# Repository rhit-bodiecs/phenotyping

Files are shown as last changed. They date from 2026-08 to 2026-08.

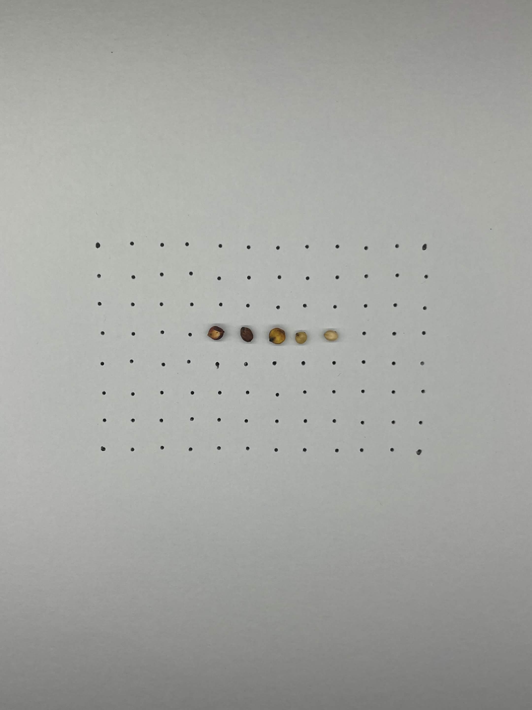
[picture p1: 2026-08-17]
ImageProcessing/demo.jpg

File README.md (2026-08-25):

# Sorghum Seed Phenotyping Automation

This repository contains prototype code and hardware design files for improving a sorghum seed phenotyping imaging pipeline.

The motivation for the project is to reduce the manual bottleneck in preparing seed samples for imaging. The current workflow requires opening a labeled packet, pouring approximately 100 seeds onto an imaging tray, manually spreading them so seeds do not touch, taking an image for downstream segmentation, and returning the seeds to the packet. Because the segmentation step expects separated seeds and is not being modified here, the hardware goal is to make seed spacing and collection faster and more repeatable.

## Demo Video

A short demo of the current prototype is available here:

[Seed phenotyping automation prototype demo](https://youtu.be/DYeSpMTDBck)

## Project Concept

The current prototype explores a vacuum-assisted positioning system:

- A perforated imaging surface biases seeds toward individual hole locations.
- A Shark WV201 handheld vacuum provides suction through a custom adapter.
- A rocking or tilting mechanism can move loose seeds around until they settle into available holes.
- After positioning, uncaptured seeds can be dumped into a collection chute while captured seeds remain held by vacuum.
- The system is being designed as modular 3D-printable parts so pieces can be tested and revised independently.

## Repository Layout

```text
.
├── 3d_models/
│   ├── seed_case_print_v1/
│   └── shark_wv201_adapter/
├── ImageProcessing/
├── nucleo-servo/
├── Time_Data.xlsx
└── README.md
```

## 3D Models

The `3d_models/` folder contains OpenSCAD source files and exported STL files from the current hardware prototype work.

### `3d_models/seed_case_print_v1/`

Separated printable parts for the modular seed imaging case and collection frame:

- `top_plate.scad` / `top_plate.stl`
- `front_wall.scad` / `front_wall.stl`
- `back_wall.scad` / `back_wall.stl`
- `left_side_wall.scad` / `left_side_wall.stl`
- `right_side_wall.scad` / `right_side_wall.stl`
- `bottom_collector_frame.scad` / `bottom_collector_frame.stl`

These parts are intended to slide together using tab-and-slot features. The bottom collector frame includes the seed collection funnel/chute and receiver grooves for the wall pieces.

### `3d_models/shark_wv201_adapter/`

Adapter prototypes for connecting the seed tray/funnel system to a Shark WV201 handheld vacuum:

- rectangular adapter prototype
- nozzle fit-test model
- rotating adapter starting model
- separated static and moving rotating-adapter pieces

These files preserve the iterative vacuum-interface work used to test nozzle fit, suction transfer, and the rotating joint concept.

## Firmware / Electronics

The `nucleo-servo/` folder is intended for embedded control work, including servo-based motion experiments. The planned control flow is:

1. Press a button to start the sequence.
2. Turn on vacuum.
3. Rock or tilt the plate to encourage seeds to settle into holes.
4. Rotate/tilt to dump uncaptured seeds into the collector.
5. Return to flat for imaging.

Future work may add camera triggering and automatic image transfer, but the current hardware/control focus is on seed positioning and mechanical automation.

## Image Processing

The `ImageProcessing/` folder contains image-processing work related to extracting phenotype data from seed images. The mechanical prototype is designed around the constraint that the segmentation step works best when seeds are separated and not touching.

## Ignored Local Artifacts

The repository ignores:

- `Figures/`
- `Phenotyping_Automation_Project.pptx`

These files are useful locally for documentation and presentation work but are excluded from version control.

## Bill of Materials

Prototype electronics and hardware links:

| Item | Link |
| --- | --- |
| BOM item 1 | [Amazon ASIN B01I8XLEM8](https://www.amazon.com/dp/B01I8XLEM8) |
| BOM item 2 | [Amazon ASIN B07HNTKSZT](https://www.amazon.com/dp/B07HNTKSZT) |
| BOM item 3 | [Amazon ASIN B08BCBZ632](https://www.amazon.com/dp/B08BCBZ632) |
| BOM item 4 | [Amazon ASIN B01ERP6WL4](https://www.amazon.com/dp/B01ERP6WL4) |

## Next Steps

- Reprint the top plate with a slightly wider/longer tray cutout so the rotating tray has enough clearance. The current printed plate is slightly too small length-wise for smooth tray rotation.
- Revise the funnel/rotating adapter model to include a printed tab at the end of the dowel/axle for connecting to the servo motor tab. The current prototype uses superglue, a loose plastic tab, and a rubber band linkage; integrating this tab directly into the printed model should make the servo linkage more reliable and repeatable.

## Current Prototype Status

The current print-ready mechanical checkpoint is `3d_models/seed_case_print_v1/`. The parts are separated for modular printing and iterative fit testing. The design is still experimental, especially the tab/slot tolerances, collector geometry, and future servo mounting/alignment.

## Tools

Primary tools used so far:

- OpenSCAD for parametric CAD
- STL exports for 3D printing
- Shark WV201 vacuum for suction testing
- STM32/Nucleo-style development target for planned servo control experiments

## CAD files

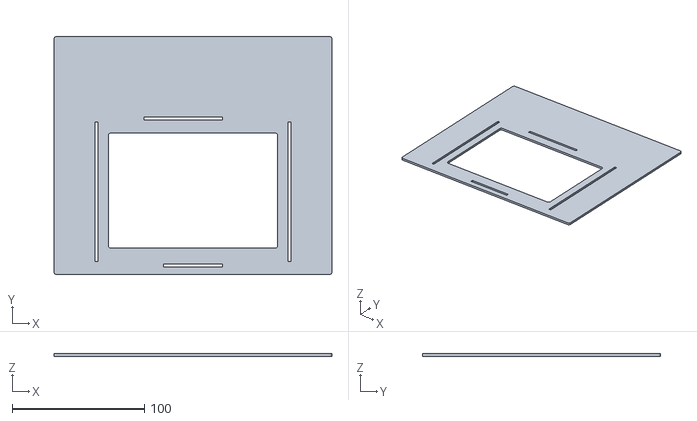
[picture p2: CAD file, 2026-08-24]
3d_models/seed_case_print_v1/top_plate.stl
210.0 x 180.0 x 2.00

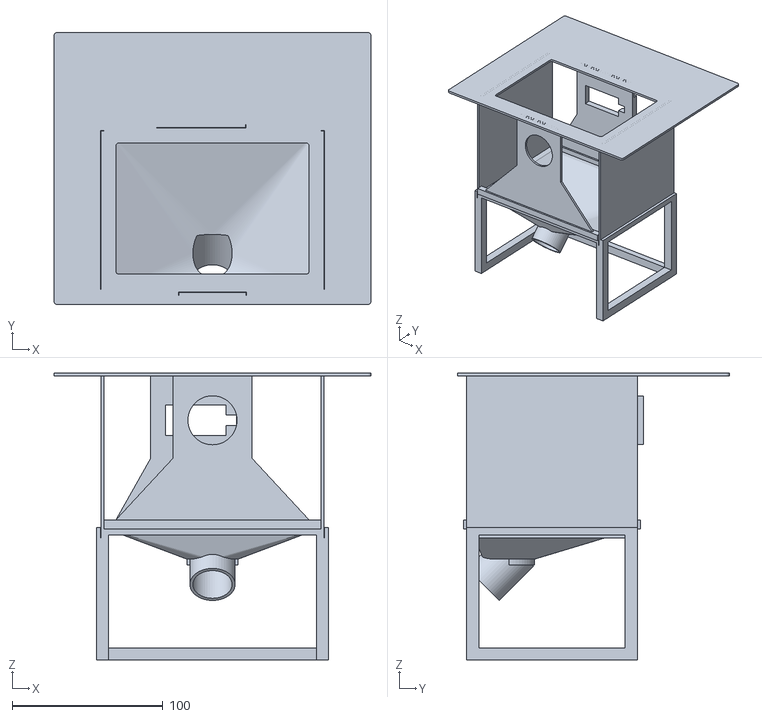
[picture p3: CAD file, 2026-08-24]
3d_models/seed_imaging_system_case_collector_ai_preview.stl
210.0 x 180.0 x 190.0

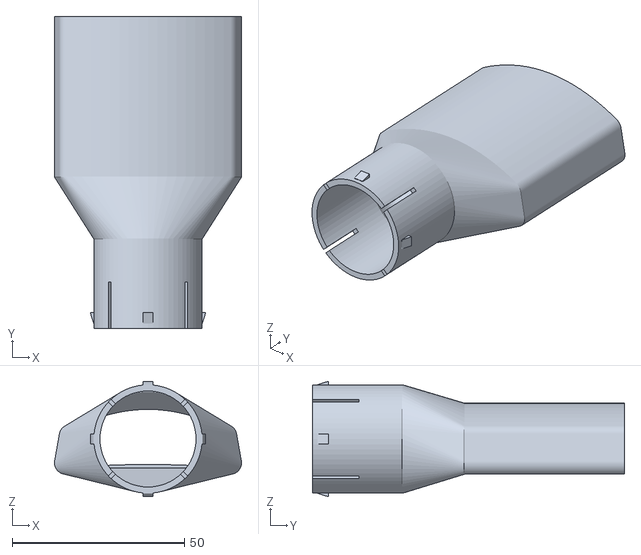
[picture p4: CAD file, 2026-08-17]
3d_models/shark_wv201_adapter/shark_wv201_rotating_adapter_static_piece_preview.stl
54.4 x 90.7 x 33.5

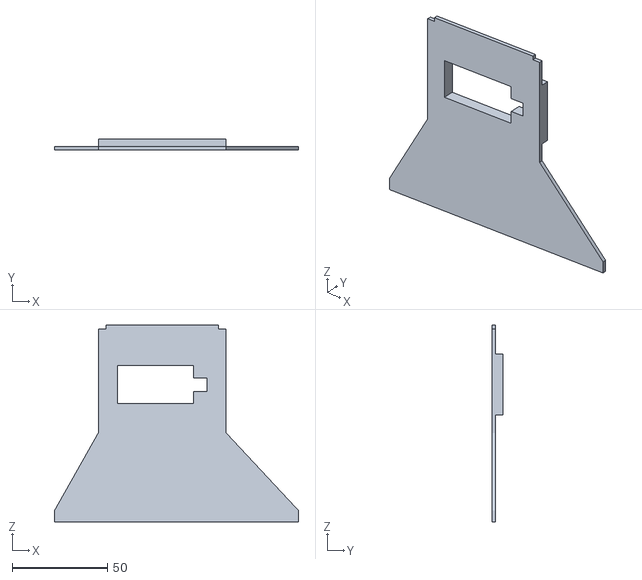
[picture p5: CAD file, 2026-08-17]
3d_models/seed_case_print_v1/back_wall.stl
128.0 x 6.00 x 103.2

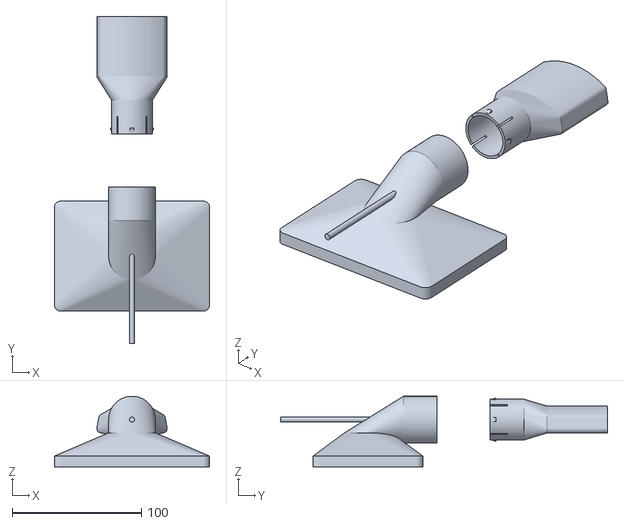
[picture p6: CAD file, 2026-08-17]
3d_models/shark_wv201_adapter/shark_wv201_rotating_adapter_v1_start_preview.stl
120.0 x 252.5 x 54.5

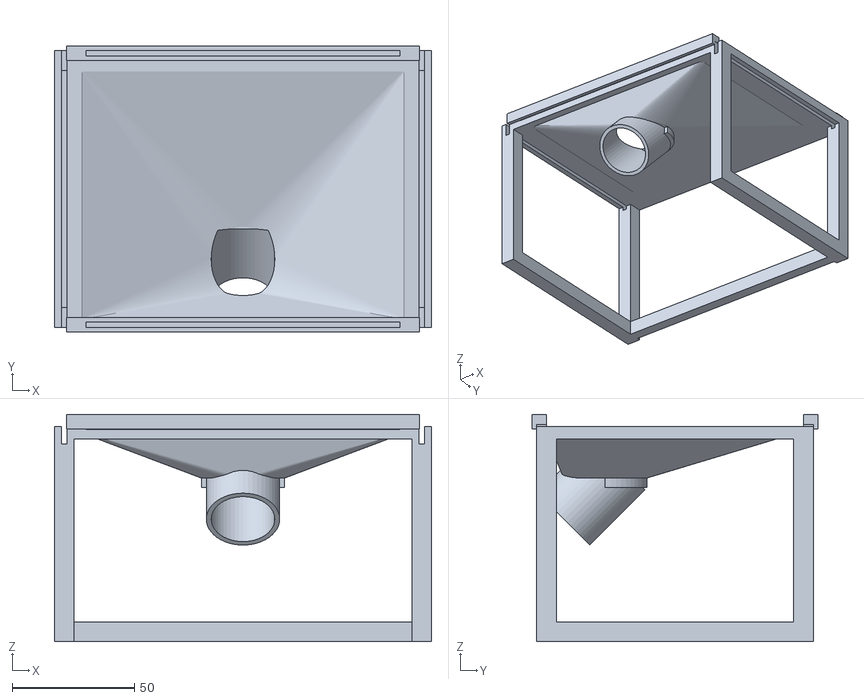
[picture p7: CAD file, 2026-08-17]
3d_models/seed_case_print_v1/bottom_collector_frame.stl
154.0 x 117.0 x 92.8

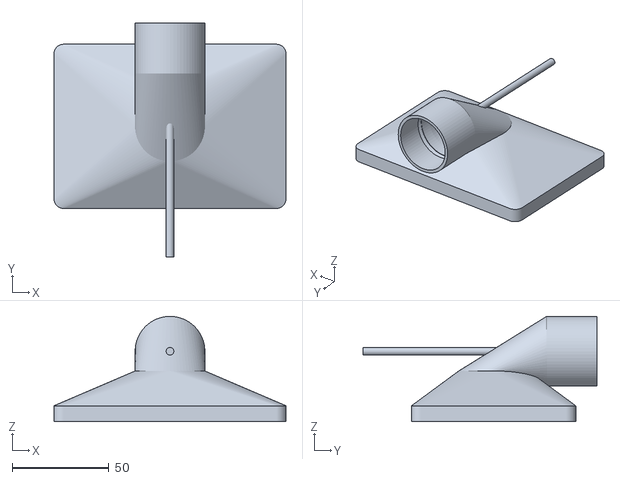
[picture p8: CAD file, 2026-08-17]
3d_models/shark_wv201_adapter/shark_wv201_rotating_adapter_moving_body_preview.stl
120.0 x 120.9 x 54.5

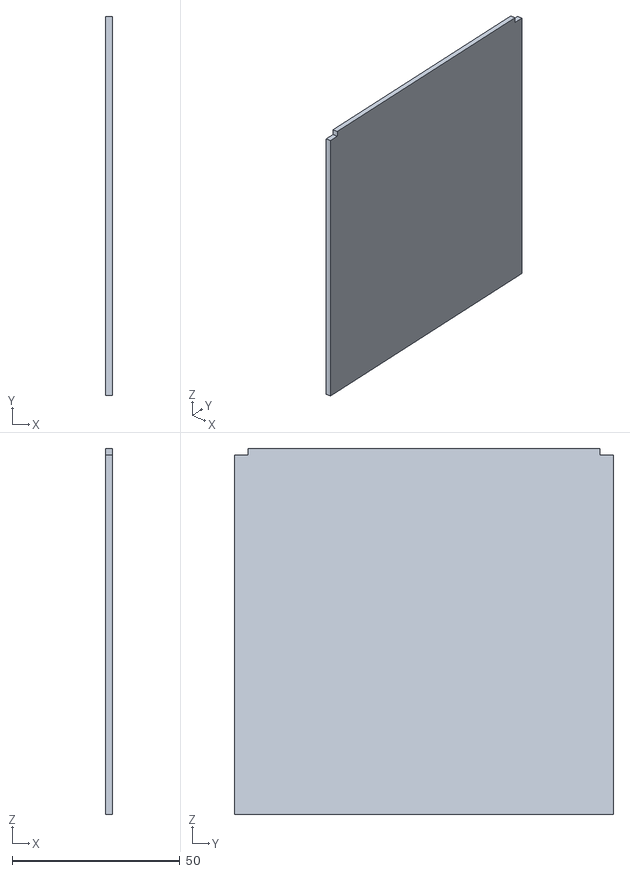
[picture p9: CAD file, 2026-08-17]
3d_models/seed_case_print_v1/left_side_wall.stl
2.00 x 113.0 x 109.2

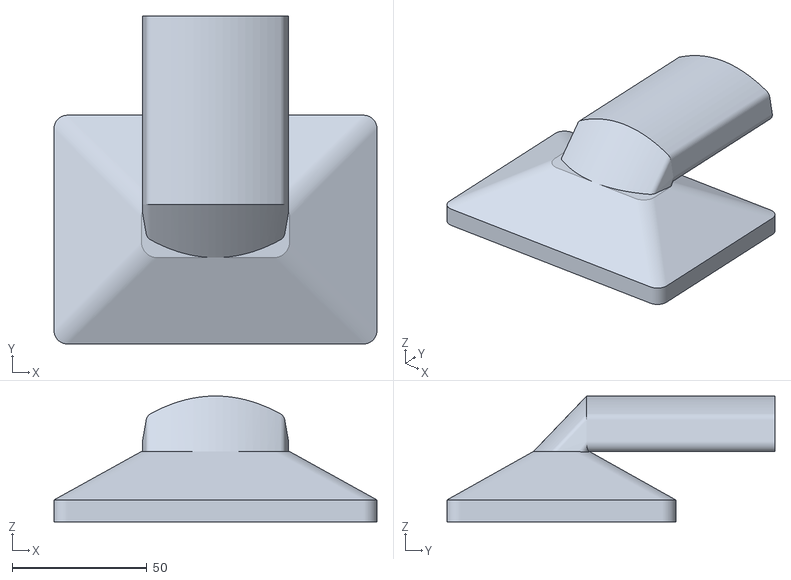
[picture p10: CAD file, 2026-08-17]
3d_models/shark_wv201_adapter/shark_wv201_rectangular_adapter.stl
120.0 x 121.9 x 46.8

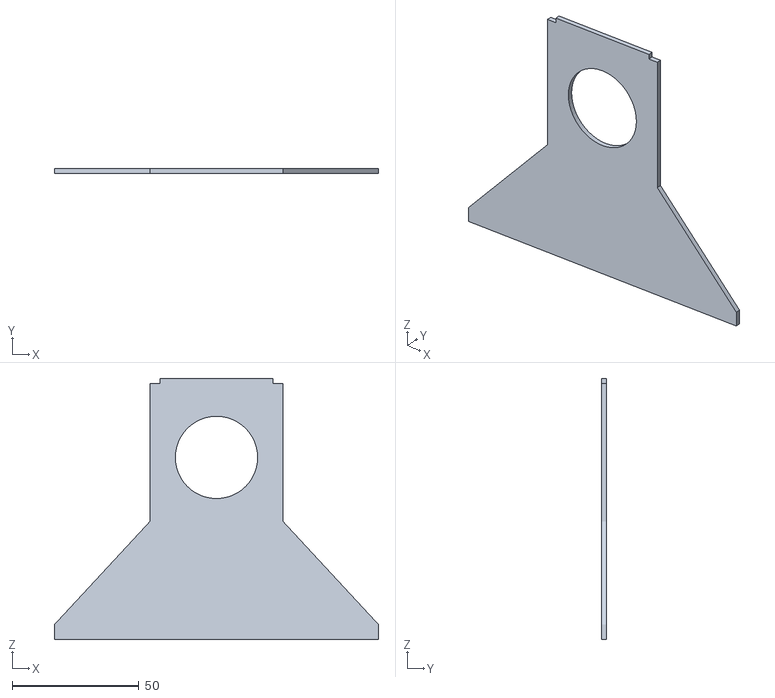
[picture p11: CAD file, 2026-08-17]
3d_models/seed_case_print_v1/front_wall.stl
128.0 x 2.00 x 103.2

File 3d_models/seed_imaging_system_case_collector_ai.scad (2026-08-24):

/*
  Seed imaging system case with experimental collector

  Starting point:
    A simple rectangular base plate for the vacuum/rocking seed imaging system.
*/

$fn = 48;

// Choose what OpenSCAD shows/exports.
part_to_show = "assembly"; // "assembly", "plate", "front", "back", "left_side", "right_side", "sides", "collector", "lower_frame", "bottom"

// Base plate dimensions.
plate_w = 210;      // mm
plate_h = 180;      // mm
plate_thick = 2;    // mm
corner_r = 2;       // mm, just enough to remove sharp corners
wall_slot_clearance = 0.3; // mm extra slot size for sliding wall parts into plate

// Cutout matching the outer tray footprint of the moving funnel adapter.
funnel_cutout_w = 124;       // mm, nominal long side for housing layout
top_plate_cutout_extra_w = 4; // mm, widens only the top plate tray cutout by 2 mm per side
funnel_cutout_h = 87;        // mm, short side plus clearance for rotation
funnel_front_gap = 20;       // mm from front long edge of plate to cutout
funnel_cutout_r = 2;         // mm, slight radius to avoid sharp internal corners
funnel_cutout_y = -plate_h/2 + funnel_front_gap + funnel_cutout_h/2;

// Front wall for the vacuum adapter interface, hanging down from the top plate.
front_wall_offset_from_cutout = 12; // mm from front edge of cutout toward plate front
front_wall_extra_w = 10;            // mm extension beyond each cutout side
front_wall_w = funnel_cutout_w + 2 * front_wall_extra_w;
front_wall_h = 101.25;              // mm, bottom is 72 mm below front circle center
front_wall_thick = 2;               // mm
front_wall_y = funnel_cutout_y - funnel_cutout_h/2 - front_wall_offset_from_cutout - front_wall_thick;
back_wall_offset_from_cutout = 10;  // mm from back edge of cutout toward plate back
back_wall_y = funnel_cutout_y + funnel_cutout_h/2 + back_wall_offset_from_cutout;
side_wall_thick = front_wall_thick;
side_wall_y = front_wall_y;
side_wall_depth = back_wall_y + front_wall_thick - front_wall_y;

// Circular opening in the front wall for the static funnel-system spout.
static_spout_outer_d = 31.5;       // mm, current static male spout OD
front_wall_spout_clearance = 1;    // mm extra diameter clearance
front_wall_spout_cutout_d = static_spout_outer_d + front_wall_spout_clearance;
front_wall_spout_top_drop = 15;    // mm below top surface of plate
front_wall_spout_center_z = plate_thick - front_wall_spout_top_drop - front_wall_spout_cutout_d/2;
front_wall_tab_margin = 10;      // mm material around circular spout tab
front_wall_tab_x = -front_wall_spout_cutout_d/2 - front_wall_tab_margin;
front_wall_tab_w = front_wall_spout_cutout_d + 2 * front_wall_tab_margin;
front_back_wall_bottom_clearance = 10; // mm below circular cutout bottom
front_back_wall_bottom_z = front_wall_spout_center_z - front_wall_spout_cutout_d/2 - front_back_wall_bottom_clearance;
front_back_wall_h = -front_back_wall_bottom_z;

// Rectangular opening in the back wall, aligned with the spout opening height.
back_wall_rect_cutout_w = 40;   // mm, long horizontal edge
back_wall_rect_cutout_h = 20;   // mm, vertical edge
back_wall_rect_cutout_x_shift = -11; // mm, left shift from spout center
back_wall_notch_size = 7;       // mm square notch centered on right edge
back_wall_notch_overlap = 0.5;  // mm overlap to avoid a zero-width seam
back_wall_tab_margin = 10;      // mm material around motor cutout tab
back_wall_cutout_min_x = back_wall_rect_cutout_x_shift - back_wall_rect_cutout_w/2;
back_wall_cutout_max_x = back_wall_rect_cutout_x_shift + back_wall_rect_cutout_w/2 + back_wall_notch_size;
back_wall_tab_x = back_wall_cutout_min_x - back_wall_tab_margin;
back_wall_tab_w = back_wall_cutout_max_x - back_wall_cutout_min_x + 2 * back_wall_tab_margin;
back_wall_servo_pad_thick = 4;    // mm extra thickness behind servo mount area
back_wall_servo_pad_margin = 6;   // mm material around the motor rectangle cutout
// Experimental lower collector dimensions.
total_system_h = 190;              // mm, target total height from top of plate to floor
floor_z = plate_thick - total_system_h;
upper_wall_bottom_z = -front_wall_h;
collector_drop_h = upper_wall_bottom_z - floor_z;
collector_wall = 2;                // mm wall thickness for chute/outlet
collector_outlet_od = 30;          // mm outer diameter for seed packet interface
collector_outlet_id = collector_outlet_od - 2 * collector_wall;
collector_outlet_len = 24;         // mm, angled tube length; shorter leaves room for the funnel slope
collector_neck_overlap = 8;        // mm overlap into throat so the angled neck and funnel connect solidly
collector_outlet_angle = 135;      // degrees; cylinder axis points 45 degrees down toward the front
collector_floor_clearance = 35;    // mm from floor to lowest outside edge of outlet mouth
collector_outlet_end_z = floor_z + collector_floor_clearance + collector_outlet_od/2;
collector_outlet_start_z = collector_outlet_end_z - collector_outlet_len * cos(collector_outlet_angle);
collector_outlet_start_y = front_wall_y + 28;
collector_outlet_end_y = collector_outlet_start_y - collector_outlet_len * sin(collector_outlet_angle);
collector_top_margin = 3;          // mm inset from inside wall span
collector_post = 8;                // mm square lower frame corner posts
collector_base_rail_h = 8;         // mm height of bottom rails
collector_base_rail_thick = 6;     // mm thickness of bottom rails
collector_lip_h = 4;               // mm thick top lip tying collector mouth into lower posts
collector_lip_overlap_up = 1;      // mm overlap into upper walls for preview/alignment before adding slots
bottom_wall_notch_depth = 6;       // mm deep receiver notch for side walls in the bottom piece
side_wall_h = front_wall_h + bottom_wall_notch_depth; // mm side walls extend into bottom notches
side_wall_top_tab_inset = 4;      // mm shorter at each end to make a shoulder stop under the top plate
front_back_wall_top_tab_inset = 4; // mm shorter at each end for front/back top plate shoulder stops
tray_boundary_wall_thick = 6;     // mm, wider than 2 mm front/back walls for future notches
tray_boundary_wall_h = 6;         // mm small raised boundary at front/back tray edges
tray_boundary_wall_x_margin = 4;  // mm extra length beyond matching front/back wall pieces
tray_boundary_wall_side_inset = side_wall_thick/2 + collector_post/2; // mm keeps rails clear of side walls
front_back_diag_frame_w = 8;      // mm width of trapezoid-frame brace bands
front_back_diag_wall_overlap = 1; // mm overlap so brace merges cleanly into front/back wall
front_back_diag_inner_base_inset = 22; // mm larger values make the inner triangle less obtuse
front_back_diag_end_inset = 14;   // mm keeps brace feet shy of side-wall/funnel corners
front_back_diag_tab_w = 12;       // mm width of rectangular feet that seat in tray-wall notches
front_back_diag_tab_h = tray_boundary_wall_h; // mm foot height matching the tray wall height
front_back_diag_notch_clearance = wall_slot_clearance; // mm extra room around brace feet

// Makes a 2D rounded rectangle profile.
module rounded_rect_2d(w, h, r) {
  offset(r = r)
    square([w - 2*r, h - 2*r], center = true);
}

// Makes the main rectangular base plate with lightly rounded corners.
module base_plate() {
  linear_extrude(height = plate_thick)
    rounded_rect_2d(plate_w, plate_h, corner_r);
}

// Cuts the moving funnel adapter tray footprint through the plate. The long
// side of the cutout runs parallel to the long side of the plate.
module funnel_tray_cutout() {
  translate([0, funnel_cutout_y, -0.5])
    linear_extrude(height = plate_thick + 1)
      rounded_rect_2d(funnel_cutout_w + top_plate_cutout_extra_w, funnel_cutout_h, funnel_cutout_r);
}

// Cuts the round spout opening through the front wall.
module front_wall_spout_cutout() {
  translate([0, front_wall_y + front_wall_thick/2, front_wall_spout_center_z])
    rotate([90, 0, 0])
      cylinder(h = front_wall_thick + 1, d = front_wall_spout_cutout_d, center = true);
}


// Makes a trapezoid-shaped wall extension with a triangular center opening.
// The two lower rectangular feet seat into matching notches in the tray wall.
module front_back_trapezoid_brace_at(wall_x, wall_w, y, y_thick) {
  top_left = wall_x;
  top_right = wall_x + wall_w;
  foot_left_center = -front_wall_w/2 + front_back_diag_end_inset;
  foot_right_center = front_wall_w/2 - front_back_diag_end_inset;
  foot_left_outer = foot_left_center - front_back_diag_tab_w/2;
  foot_left_inner = foot_left_center + front_back_diag_tab_w/2;
  foot_right_inner = foot_right_center - front_back_diag_tab_w/2;
  foot_right_outer = foot_right_center + front_back_diag_tab_w/2;
  z_top = front_back_wall_bottom_z + front_back_diag_wall_overlap;
  z_bottom = upper_wall_bottom_z;
  z_foot_top = upper_wall_bottom_z + front_back_diag_tab_h;
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

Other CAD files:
3d_models/seed_case_print_v1/right_side_wall.stl
3d_models/seed_case_print_v1/back_wall.scad
3d_models/seed_case_print_v1/bottom_collector_frame.scad
3d_models/seed_case_print_v1/front_wall.scad
3d_models/seed_case_print_v1/left_side_wall.scad
3d_models/seed_case_print_v1/right_side_wall.scad
3d_models/seed_case_print_v1/top_plate.scad
3d_models/shark_wv201_adapter/shark_wv201_nozzle_fit_test_current.scad
3d_models/shark_wv201_adapter/shark_wv201_rectangular_adapter.scad
3d_models/shark_wv201_adapter/shark_wv201_rotating_adapter_moving_body.scad
3d_models/shark_wv201_adapter/shark_wv201_rotating_adapter_static_piece.scad
3d_models/shark_wv201_adapter/shark_wv201_rotating_adapter_v1_start.scad

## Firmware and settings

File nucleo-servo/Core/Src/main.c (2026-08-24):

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
/* Includes ------------------------------------------------------------------*/
#include "main.h"



TIM_HandleTypeDef htim8;

/* USER CODE BEGIN PV */
static const uint16_t SERVO_MIN_US    = 500U;
static const uint16_t SERVO_CENTER_US = 1500U;
static const uint16_t SERVO_MAX_US    = 2500U;
static const uint16_t SERVO_JITTER_US = 200U;
static const uint16_t SERVO_QUARTER_US = 675U;

static const uint16_t SERVO_START = SERVO_CENTER_US - SERVO_QUARTER_US;
static const uint16_t SERVO_DUMP = SERVO_CENTER_US + SERVO_QUARTER_US;

static const uint16_t JITTER_DELAY = 125;
static const uint16_t JITTER_COUNT = 20;
/* USER CODE END PV */

void SystemClock_Config(void);
static void MX_GPIO_Init(void);
static void MX_TIM8_Init(void);
/* USER CODE BEGIN 0 */
static void servo_write_us(uint16_t pulse_us)
{
    /*
     * Keep the pulse within a conservative initial range.
     * Expand this only after confirming the servo does not hit its stops.
     */		
    if (pulse_us < SERVO_MIN_US) {
        pulse_us = SERVO_MIN_US;
    }

    if (pulse_us > SERVO_MAX_US) {
        pulse_us = SERVO_MAX_US;
    }

    __HAL_TIM_SET_COMPARE(&htim8, TIM_CHANNEL_2, pulse_us);
}

void dump_sequence(void)
{	
	//jitter for about one second
	for(int i = 0; i < JITTER_COUNT; i++){
		servo_write_us(SERVO_START + SERVO_JITTER_US);
		HAL_Delay(JITTER_DELAY);

		servo_write_us(SERVO_START - SERVO_JITTER_US);
		HAL_Delay(JITTER_DELAY);
	}
	
	servo_write_us(SERVO_START);
	HAL_Delay(2000);
	servo_write_us(SERVO_DUMP);
	HAL_Delay(2000);
	servo_write_us(SERVO_START);

}
/* USER CODE END 0 */

/**
  * @brief  The application entry point.
  * @retval int
  */
int main(void)
{

  /* MCU Configuration--------------------------------------------------------*/

  /* Reset of all peripherals, Initializes the Flash interface and the Systick. */
  HAL_Init();

  /* Configure the system clock */
  SystemClock_Config();

  /* Initialize all configured peripherals */
  MX_GPIO_Init();
  MX_TIM8_Init();
  /* USER CODE BEGIN 2 */
if (HAL_TIM_PWM_Start(&htim8, TIM_CHANNEL_2) != HAL_OK) {
    Error_Handler();
}

servo_write_us(SERVO_START);
HAL_Delay(1000);
  /* USER CODE END 2 */

  /* Initialize leds */
  BSP_LED_Init(LED2);

  /* Initialize USER push-button, will be used to trigger an interrupt each time it's pressed.*/
  BSP_PB_Init(BUTTON_USER, BUTTON_MODE_EXTI);

  /* Infinite loop */
  /* USER CODE BEGIN WHILE */
  while (1)
  {
	if(HAL_GPIO_ReadPin(GPIOC, GPIO_PIN_13) == GPIO_PIN_RESET)
	{
		dump_sequence();

		//wait for release
		while(HAL_GPIO_ReadPin(GPIOC, GPIO_PIN_13) == GPIO_PIN_RESET)
		{
			HAL_Delay(10);
		}
	}
	HAL_Delay(10);

    /* USER CODE END WHILE */

    /* USER CODE BEGIN 3 */
  }
  /* USER CODE END 3 */
}

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


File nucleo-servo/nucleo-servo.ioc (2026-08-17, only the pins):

Mcu.UserName=STM32F446RETx
PA13.GPIO_Label=TMS
PA13.Signal=SYS_JTMS-SWDIO
PA14.GPIO_Label=TCK
PA14.Signal=SYS_JTCK-SWCLK
PA2.GPIO_Label=USART_TX
PA2.Signal=USART2_TX
PA3.GPIO_Label=USART_RX
PA3.Signal=USART2_RX
PA5.Signal=GPIO_Output
PB3.GPIO_Label=SWO
PB3.Signal=SYS_JTDO-SWO
PC13.Signal=GPXTI13
PC14-OSC32_IN.Signal=RCC_OSC32_IN
PC15-OSC32_OUT.Signal=RCC_OSC32_OUT
PC7.Signal=S_TIM8_CH2
PH0-OSC_IN.Signal=RCC_OSC_IN
PH1-OSC_OUT.Signal=RCC_OSC_OUT

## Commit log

2026-08-17 added 3d models
    [back_wall.scad, back_wall.stl, bottom_collector_frame.scad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]
2026-08-24 Update seed housing models and BOM
    [seed_imaging_system_case_collector_ai.scad, seed_imaging_system_case_collector_ai_preview.stl, top_plate.scad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]

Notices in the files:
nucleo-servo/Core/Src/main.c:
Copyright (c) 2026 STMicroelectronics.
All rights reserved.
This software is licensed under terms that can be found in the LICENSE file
